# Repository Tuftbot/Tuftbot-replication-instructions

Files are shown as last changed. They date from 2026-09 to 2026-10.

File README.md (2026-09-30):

# Tuftbot replication instructions
In this repository you can find the technical documentation necessary to replicate the project Tuftbot, a robotic arm set up for tufting. Project developed during the project LAUDS Factory Open Call02 by Landscape Choreography and Lowpoly 

The project aims to establish an innovative microfactory model combining collaborative robotics with traditional textile craftsmanship to valorize European regional wool varieties which are mainly discarded. Primary objectives include developing a sustainable production system for artistic creation, optimizing robotic tufting for autochthonous wool processing, and creating a replicable model for small-scale textile manufacturing that bridges artisanal quality with automated efficiency. Through the development of robotic tufting technology the goal is to allow the activation of supply chains that can be local, from resource extraction to product retail, in order to keep the value produced within rural context. This model is opposed to global extractive value chains.

During the project LAUDS Open Call 2 Lowpoly and Landscape Choreography collaborated, with the support of SUPSI Fablab, to the development of a pilot for tufting with a robotic arm using local coarse wool. From the beginning the project was focused on optimising the work already developed by Lowpoly on robotufting with the requirements given by working with local coarse wool, and with the objective of designing a system replicable wherever there is access to a robotic arm.
To do so all the technical development was done in parallel at Lowpoly studio in Madrid, using an ABB IRB1200 model and at SUPSI Fablab in Medrisio using a KUKA KR6/16/20-3
In the Lowpoly setup, the robot is relatively small and mounted on a wheeled table. Since there are no significant spatial movement constraints, the robot can be moved around and beyond the studio, allowing the frames to be positioned almost 360° around it. In the SUPSI case, being the Fablab within a University, due to safety requirements also connected to the larger size and weight of the robot, the range of motion of the axes was limited. We therefore adapted the development of the project not only to the requirements given by each specific robot model but also to the restrictions given by the prototyping space.

In the following documentation you will find, in parallel, information on the two pilot tests developed.

In [01_Robot-Hardware.md](01_Robot-Hardware.md) you can find all the information on the hardware needed to replicate the Tuftbot.
In some cases you will find the links to the online shops where we acquired the components, for the custom made pieces you will find the 3D models that you will be able to further customise to your needs and 3D print.

In [02_Robot-Software.md](02_Robot-Software.md) you can find the links to the software we developed, links to the plug in we used and a explanation, piece by piece, of the grasshopper file we developed.

In [03_Tufting-equipment.md](03_Tufting-equipment.md) you can find a description of the tufting tools we opted for. One of the goal was to experiment with biobased and biodegradable materials. Like in other repositories you will find the link to the shops where we sourced our materials.

In [04_Comparing_two_set_up.md](04_Comparing_two_set_up.md) you can find a description of the two set up we experimented with. One in Madrid at Lowpoly studio using an ABB IRB1200 and one at SUPSI Fablab in Medrisio using a KUKA KR6/16/20-3.

In [05_Production_Workflow.md](05_Production_Workflow.md) you can find a step by step description of the workflow, from an image to the robot tufting process.

In [06_Native_coarse_wool.md](06_Native_coarse_wool.md) you can find a description of our research into native wool varieties, why is important for the project and the specifics of the yarns we developed.

In [07_Tiles_generator.md](07_Tiles_generator.md) you can find a description of the tiles generator we developed and link its Html file.

In [08_Tests_and_iterations.md](08_Tests_and_iterations.md) you can find a brief description of the evolution of the project, from first samples to final products. We chose to share this so it might help you in the adjustment that your specific replication project will require.

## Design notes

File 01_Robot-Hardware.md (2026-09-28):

## Hardware

### Robot minimum specifications

The payload needs to be minimum 3,5/ 5 kg in order to carry a 1kg gun in order to resist the backfire while tufting. 

Maximum printing area calculation according to robot dimensions

Given a certain arm extension the printing area can be calculated as follow:

| Type of robotic arm tested | Measures arm | Measures max tufting area |
| --- | --- | --- |
| KUKA KR6/16/20-3 | 1611 x 1320 x 138 mm | 1464 x 2025 mm |
| ABB IRB1200 | 539 x 869 x 115 mm  | 703 x 1102 mm |

- KUKA KR6/16/20-3:
  
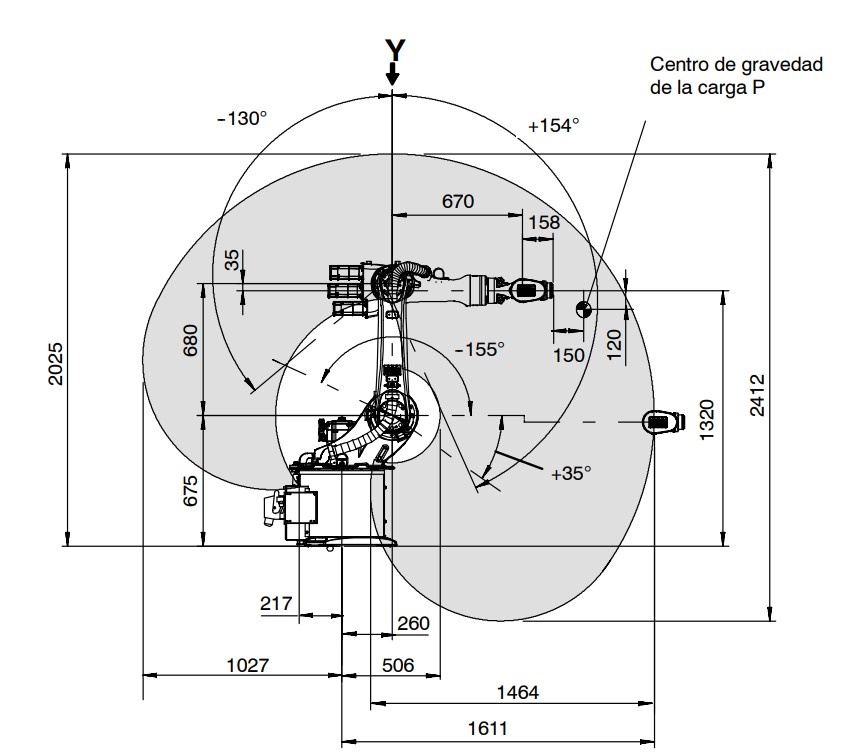
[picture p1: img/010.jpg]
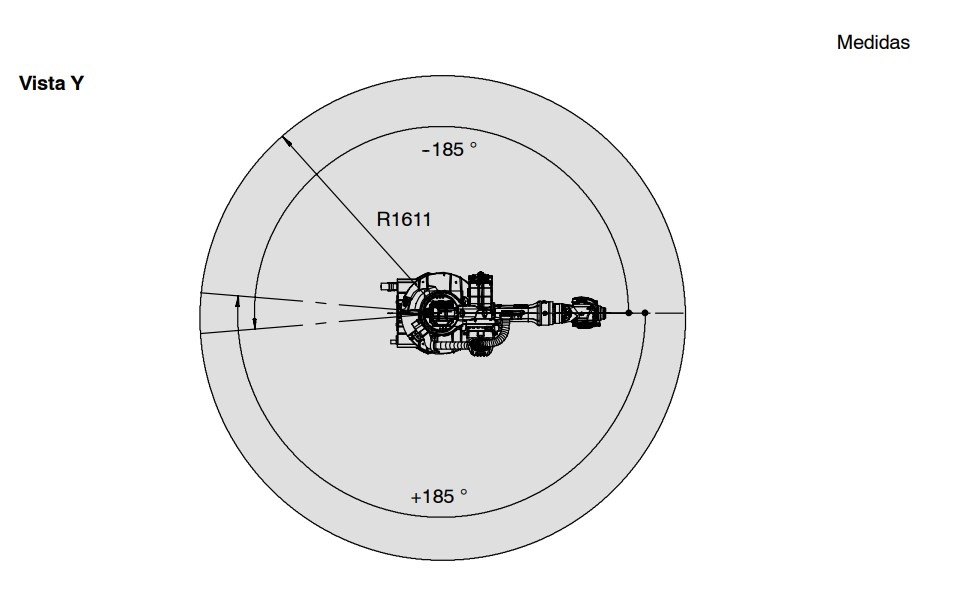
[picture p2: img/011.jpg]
  

- ABB IRB1200:

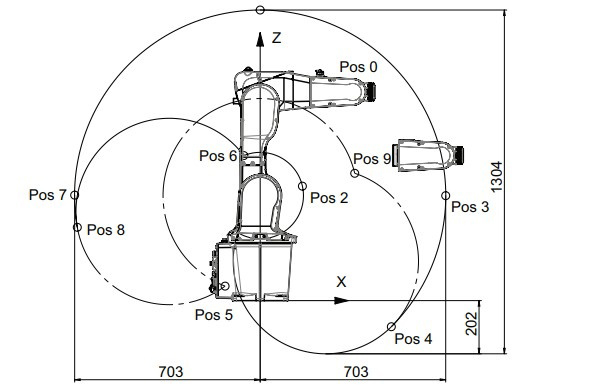
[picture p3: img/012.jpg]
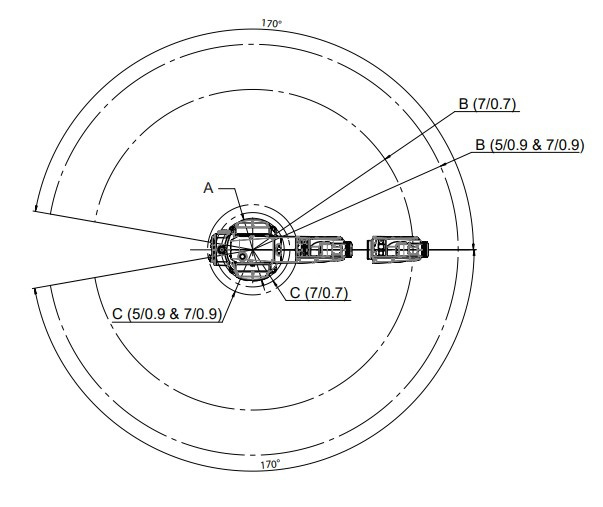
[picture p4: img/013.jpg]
    

### List of components 

### End effector 

The end effector is 3d printed. It is composed of two parts, one that gets attached to the robot and needs to be custom made for each robot, and one that is made for standard tufting guns. This second part has holes with a margin in order to adapt to the subtle differences of each gun. 

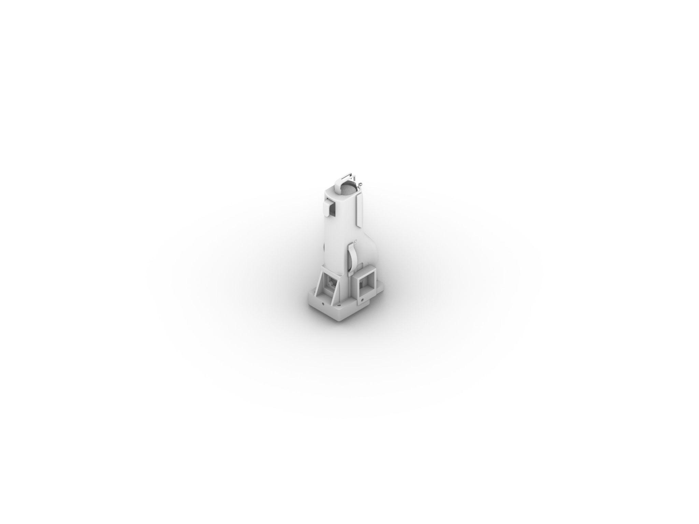
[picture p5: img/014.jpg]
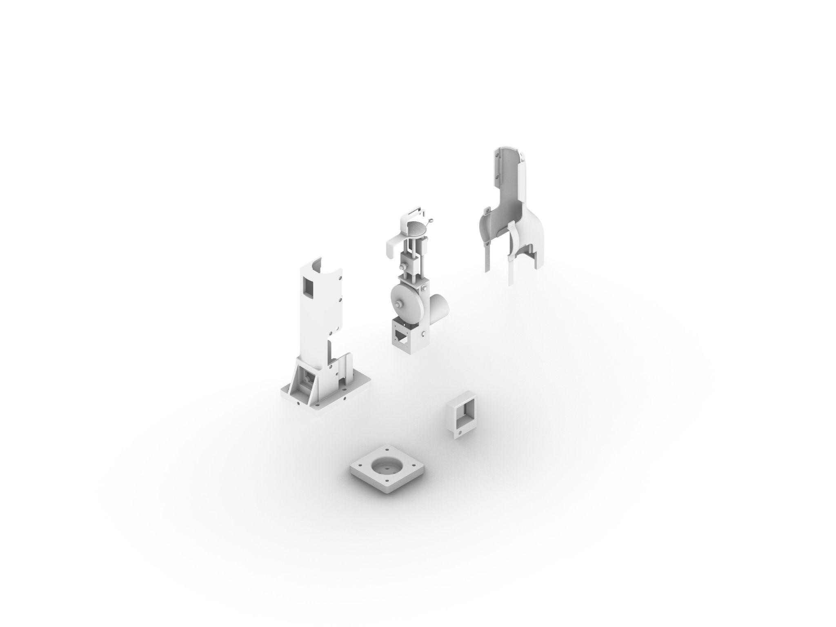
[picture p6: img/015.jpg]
 

To see 3d files go to this [folder](Files/Hardware-Files)

Here you can see an image of the end effector printed and mounted on the KUKA at SUPSI.

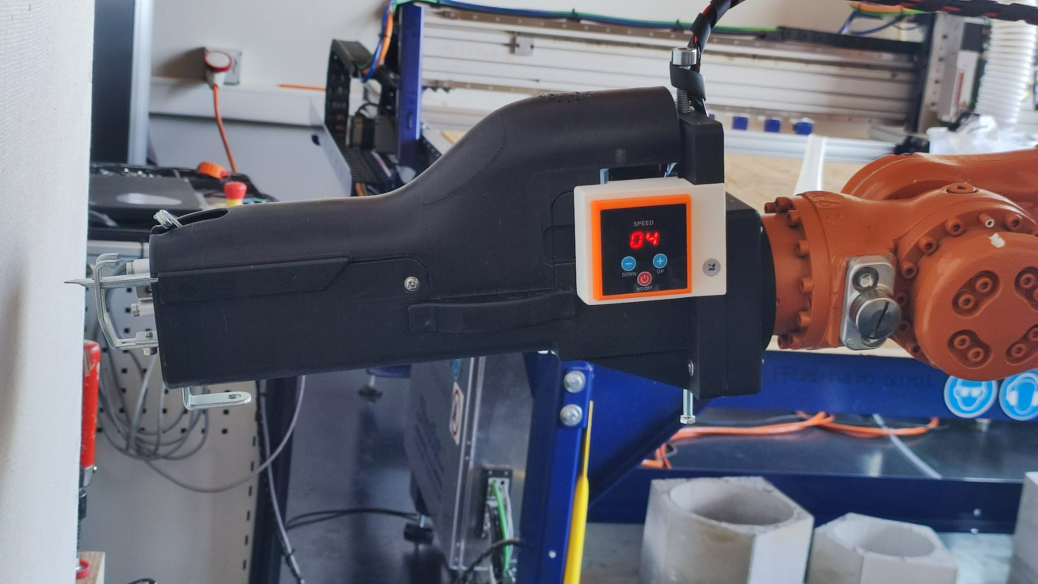
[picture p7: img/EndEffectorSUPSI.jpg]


 ### Sensors

We chose to test industrial sensors already used in textile machinery. There are two kinds of sensors, one to see if the yarn is present and one to detect if it’s moving. They are both fundamental to try to automatize the tufting process.

The robotic arm can turn the tufting gun on/off and read sensors that check if the yarn is running. Two sensors are used: a hall-effect sensor that detects rotation while yarn moves, and a vibration sensor that detects yarn motion; if either fails, the arm and gun stop so the operator can replace the yarn, then restart. However, the system can’t confirm that each stitch was actually inserted into the canvas, the gun’s own vibrations can trick the vibration sensor, and the hall-effect sensor can lose the yarn, making the whole stop–replace–restart flow unreliable.

The following sensors have been tested: [DC12-24V NPN PNP induction sensor Switch](https://it.aliexpress.com/item/1005002883343587.html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) and [Twisting Yarn Sensor Wire Device ](https://it.aliexpress.com/item/4000093115538.html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)

Vibration sensor with yarn

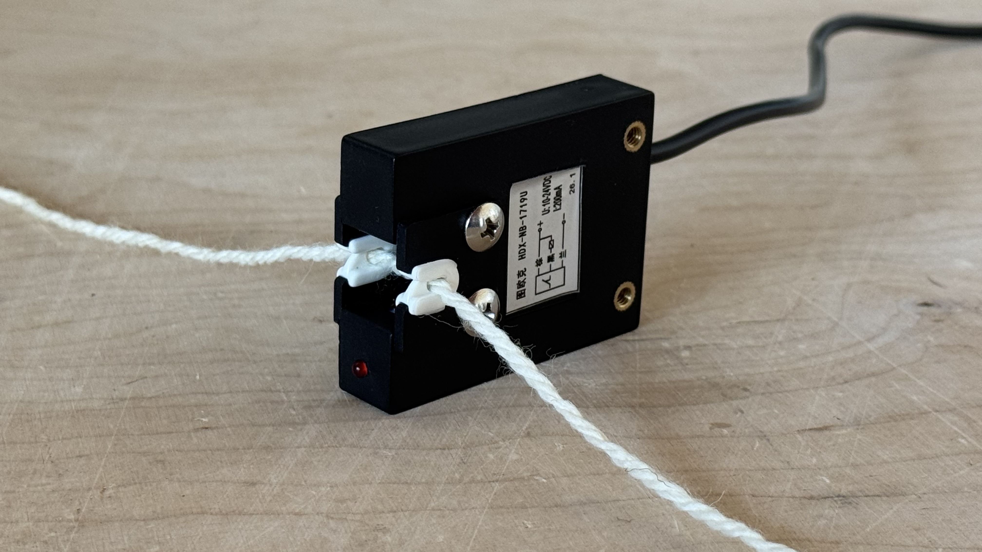
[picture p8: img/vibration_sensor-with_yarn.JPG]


Hall effect sensor with yarn

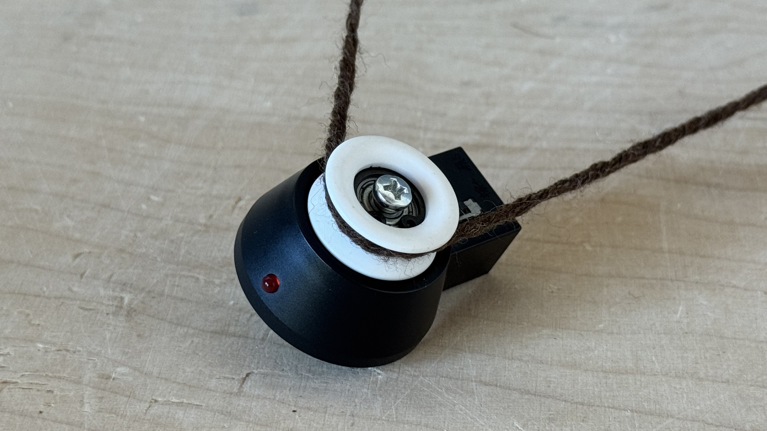
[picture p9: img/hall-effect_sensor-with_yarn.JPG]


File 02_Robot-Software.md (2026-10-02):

## Robot Software

### Links and plug in

[KUKA|prc (KUKA KR6/16/20-3)](https://www.food4rhino.com/en/app/kukaprc-parametric-robot-control-grasshopper)

Vectorize (package manager Rhino and plugin for grasshopper)

[Treesloth (package manager Rhino)](https://www.food4rhino.com/en/app/treesloth)

Robots (ABB IRB1200)(package manager Rhino)

[Image processing](Files/Software-Files/01_Image_processing)
A Grasshopper file used to convert the image into a toolpath.

[Robot Tufting KUKA](Files/Software-Files/02_Robot_Tufting_KUKA)
Grasshopper version for generating the code to be sent to the KUKA robot.

[Robot Tufting ABB](Files/Software-Files/03_Robot_Tufting_ABB)
Grasshopper version for generating the code to be sent to the ABB robot.

[Multiframe ABB Simulation](Files/Software-Files/04_Multiframe_ABB_Simulation)
Definition of Simulation for Multiframe Operations.

### Plugin install for KUKA
All the needed plugins can be automatically downloaded at the first opening of the Grasshopper file, one plugin will be missing called Treesloth, Treesloth1 or similar.

The plugin Treesloth needs to be downloaded by the provided link and the resulting GHA file should be manually moved into the componenets folder of Grasshopper.
You can open the folder by opening grasshopper then File > Special Folders > Component Folder
After moving the GHA file manually you can restart Rhino and the plugin will be installed

### General file usage
The file for ABB is using Robots as a plugin, this plugin can be used with most of the robotic arms. The KUKA version is using KUKA PRC that is specifically designed for KUKA robotic arms.
All the files are exported for Rhino8, in case you have a previous generation of rhinoceros you can use the plugin https://www.food4rhino.com/en/app/convert3dm to convert files

### Grasshopper code for single frame 

Image processing (JPEG format for correct script operation) using the Vectorize plugin, distinguishing between two zones: the one corresponding to the color white and the one corresponding to the color brown.

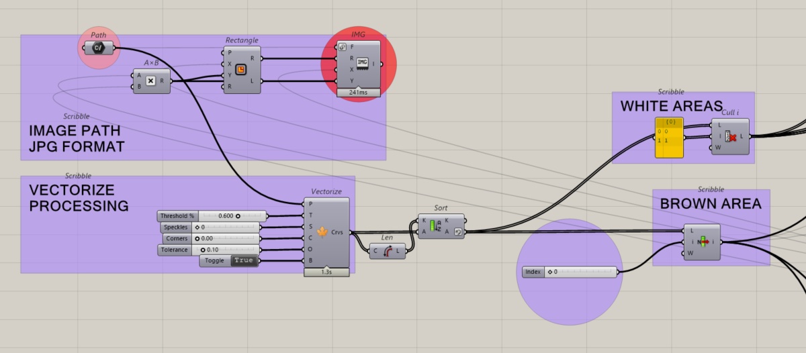
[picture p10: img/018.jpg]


The white areas are calculated by interpolating the outer lines, such that three curves are knitted for each of the shapes.

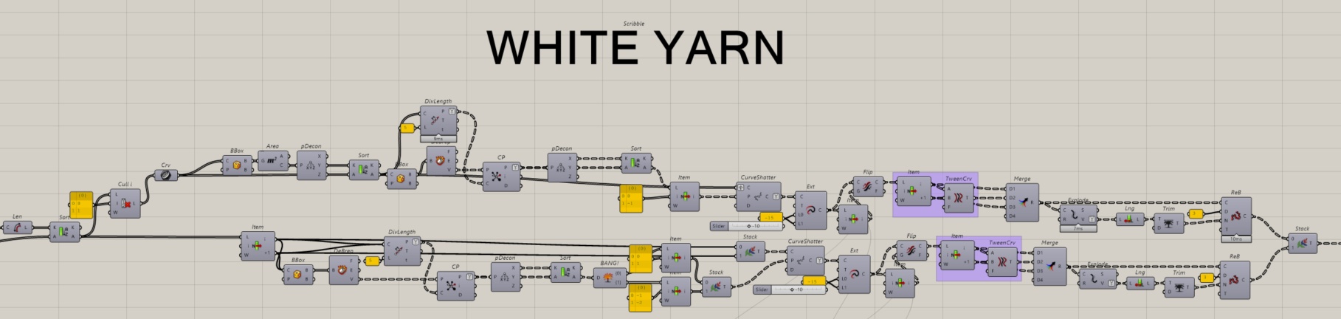
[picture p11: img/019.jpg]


In the brown area, a pattern of parallel lines is established with a minimum spacing of 5 mm to prevent the canvas from tearing. Where they intersect with white areas, the lines are interrupted and resume at the end of that area. Line segments shorter than 20 mm are omitted to prevent the canvas from tearing.

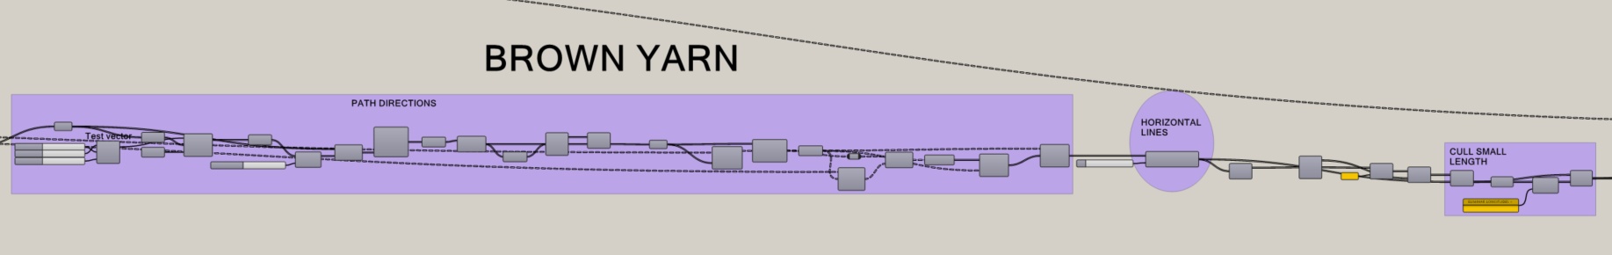
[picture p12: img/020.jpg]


The obtained curves are organized into two blocks (white/brown), and the direction of the curves, which the robot will follow, is established.
The file containing the curve geometry is divided into two main blocks. 

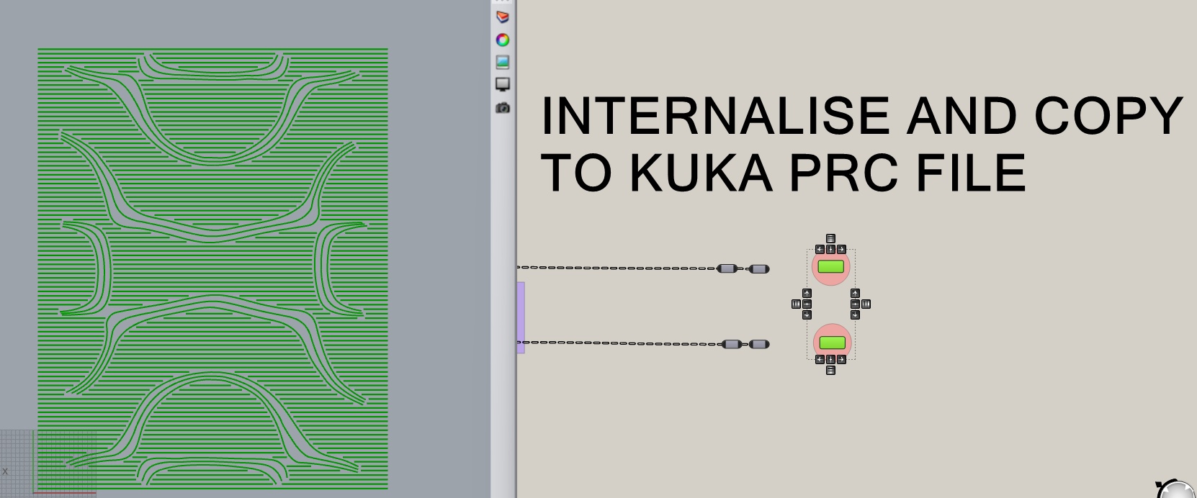
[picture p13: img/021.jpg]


The two curve blocks are oriented and positioned. The curves are converted into polylines to adjust the robot's movement precision.

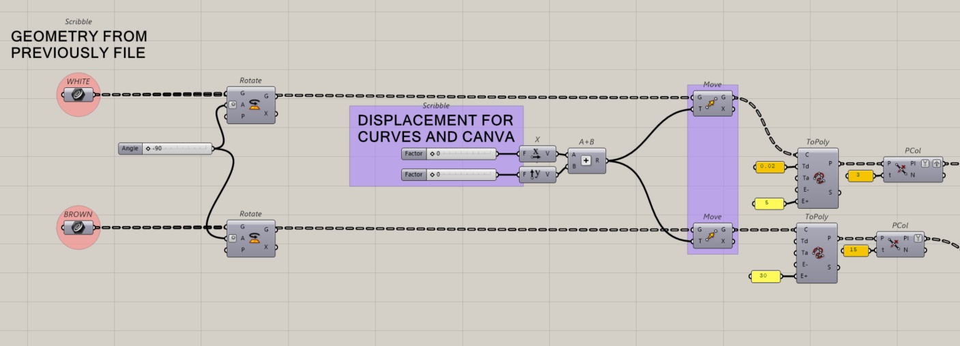
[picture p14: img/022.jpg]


The initial and final positions of the robot are established.

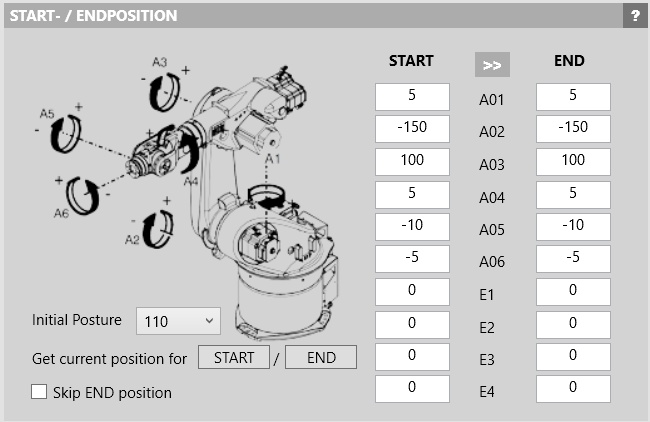
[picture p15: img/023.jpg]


We include an initial calibration point that aligns with one of the frame's corners. This allows the frame's position to be verified, or readjusted if necessary, at the start of the program's execution.

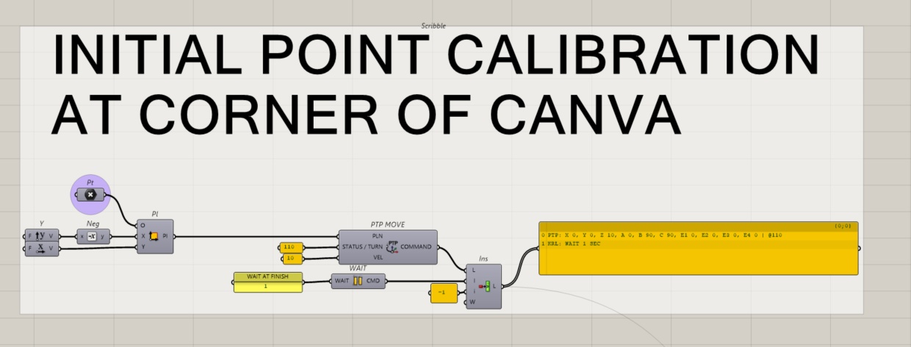
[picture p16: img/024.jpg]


The robot begins tufting the white lines. Digital output pins are used to activate and deactivate the tufting gun, as well as to light up a green indicator lamp showing that the robot is in operation.

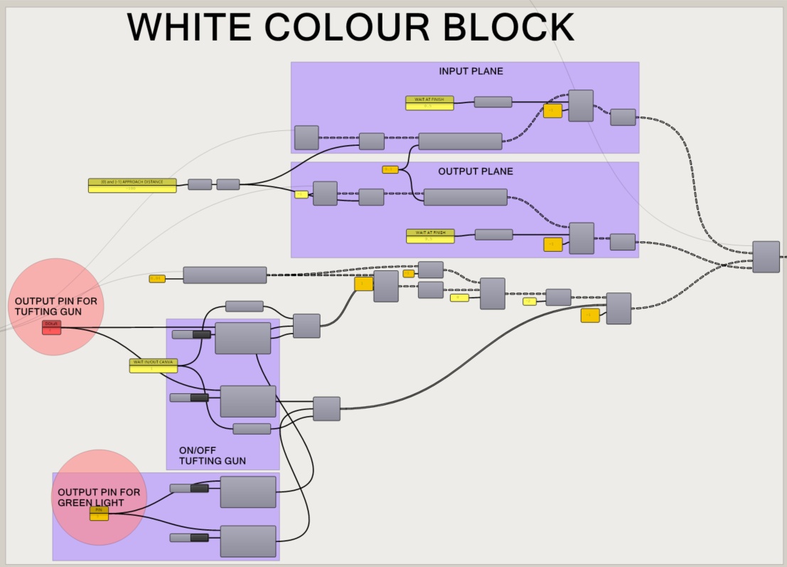
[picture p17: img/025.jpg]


When the first block is completed, the robot deactivates the green DO, activates the red DO, and moves to a preset rest position to proceed with the thread color change.
Once the thread has been changed, a pushbutton, configured via a DI, must be used to make the robot resume movement.

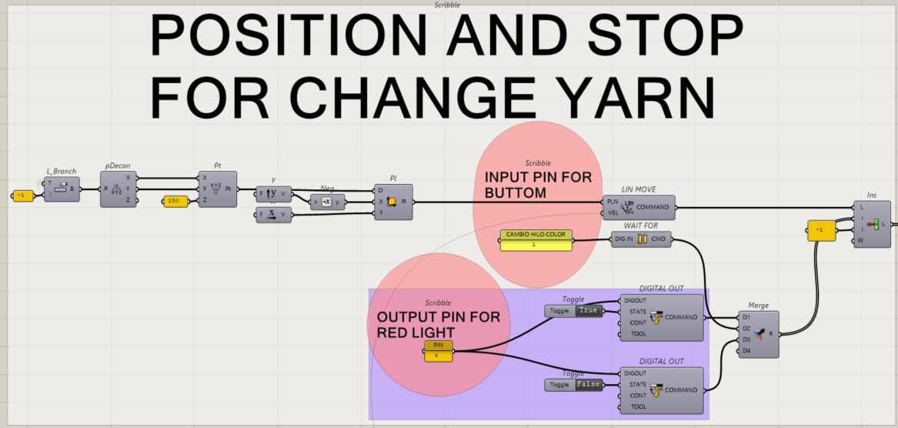
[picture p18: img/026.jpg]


The robot begins weaving the brown lines. Digital output (DO) pins are used to activate and deactivate the tufting gun, as well as to light up a green indicator showing that the robot is in operation. Once finished, the robot returns to its starting position.

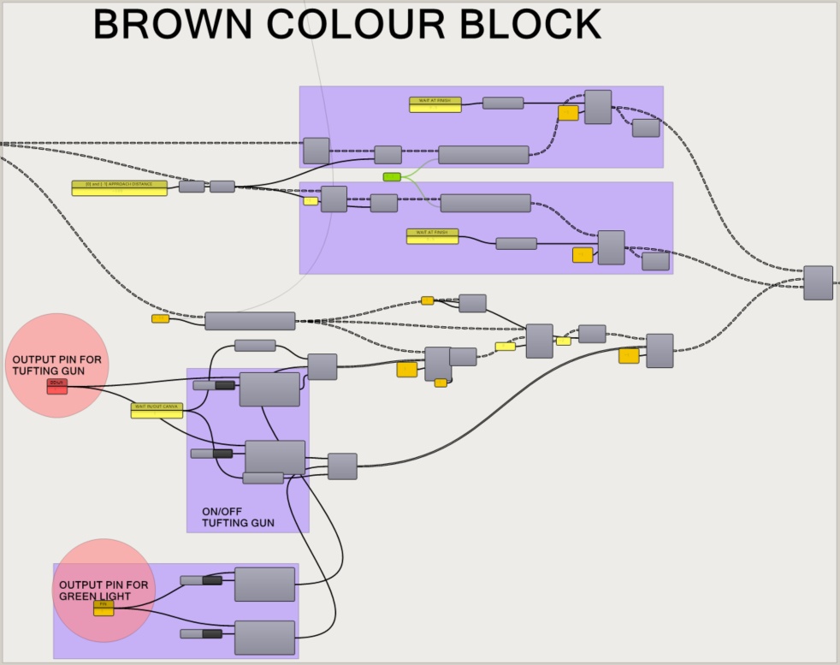
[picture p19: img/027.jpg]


All planes and commands to be executed by the robot are connected to the KUKA|prc CORE component. The geometry of the gun is also connected to it, allowing us to simulate the toolpath and verify whether the canvas position is correct, check for collisions, singularities, etc., and make any necessary corrections.

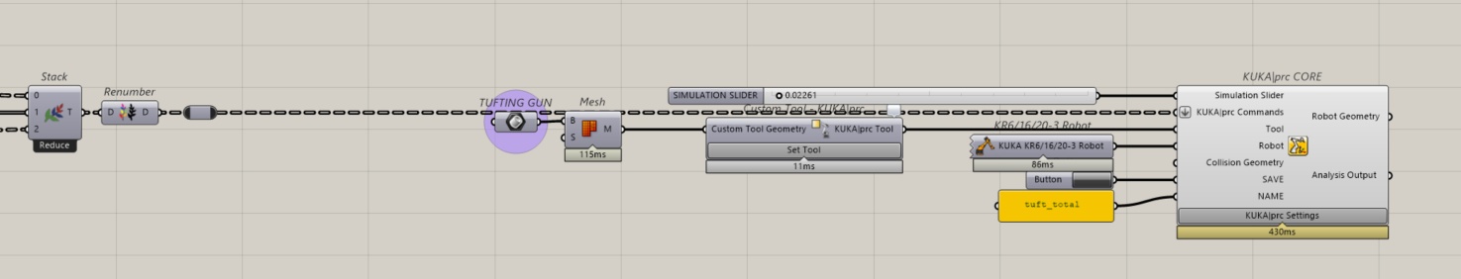
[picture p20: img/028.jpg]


### Grasshopper code for multi frame

The workflow for the multi-frame system follows the same steps previously described for image processing.
The robot executes the white thread lines for both frames, pauses to switch threads, and finally executes all the parallel brown lines for both frames.
This scenario has been simulated using the ABB IRB1200 robot.

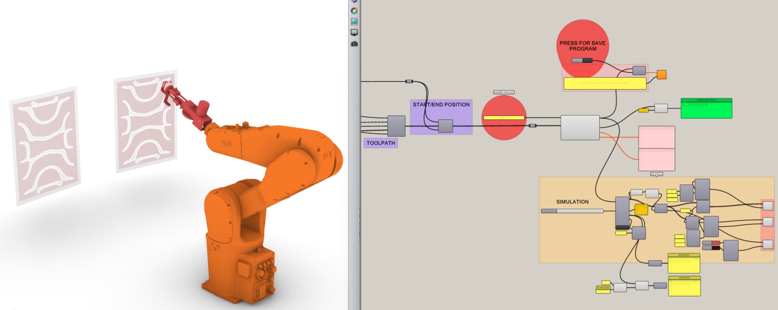
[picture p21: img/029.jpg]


The geometry of both frames connects to the "Create program" component of the Robots plugin, allowing us to simulate the toolpath and verify the positioning of both canvases, checking for collisions, singularities, and the like, so that any issues can be corrected.

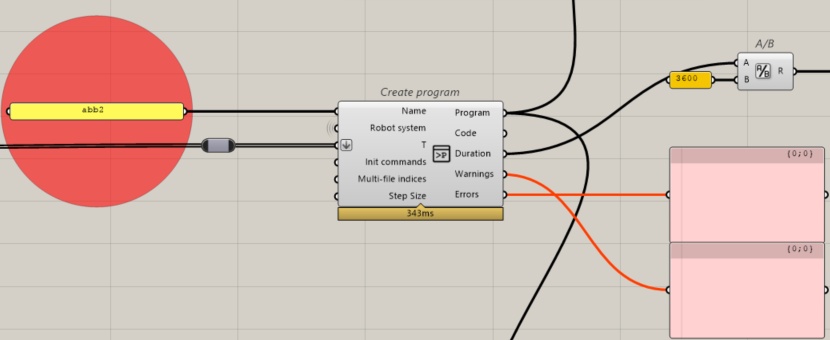
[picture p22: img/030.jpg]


### Description on how to make the set up and use it to tuft

Position the frame according to the base coordinates specified in KUKA|prc CORE.
When the toolpath .src file is executed for the first time, the initial position assumed by the robot serves as the final calibration.

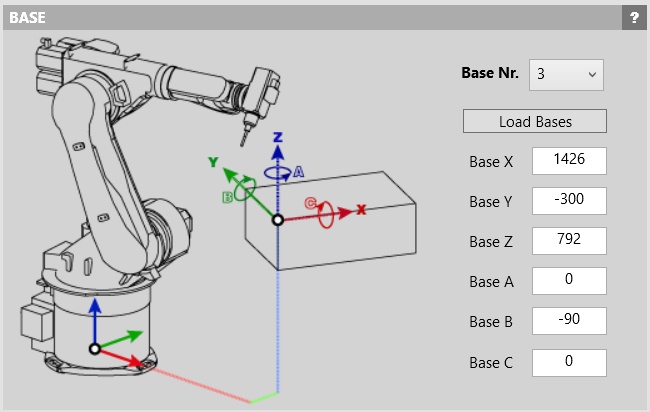
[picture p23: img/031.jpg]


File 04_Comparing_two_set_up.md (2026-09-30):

### Comparing two set up

Set up at Lowpoly in Madrid (left), Set up at SUPSI Fablab in Mendrisio (right).

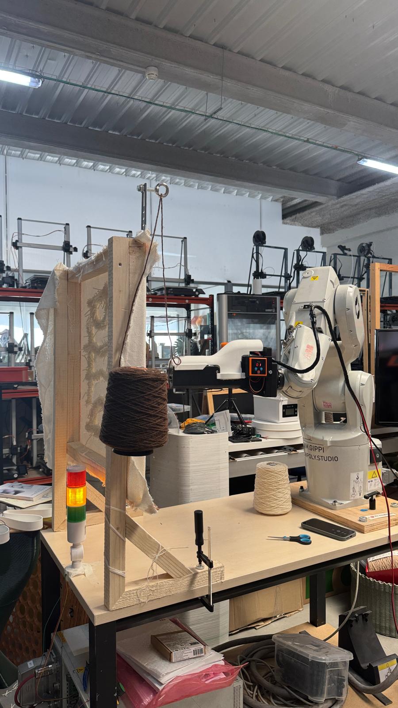
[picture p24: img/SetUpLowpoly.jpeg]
 

Both prototypes are based on the same image (JPEG format, to ensure the script works correctly).
The drawing was done by Eva Failla di [Studio Converter](https://studioconverter.com/).

 

The image undergoes vectorization using the Vectorize plugin, distinguishing between two zones: the one corresponding to the color white and the one corresponding to the color brown.



The lines are spaced at least 5 mm apart to prevent the canvas from tearing during the execution of the pattern.
Line segments shorter than 20 mm are omitted to avoid tearing the canvas.
The resulting curves form the toolpath that the robot will follow. In Mendrisio, this is carried out using a KUKA KR6/16/20-3 model, while in Madrid, an ABB IRB1200 model is used.
The image used at both locations measures 400 x 500 mm.
The positioning of the robot relative to the frame holding the canvas is as follows:

Mendrisio (KUKA KR6/16/20-3):





Madrid (ABB IRB1200):



An end effector with the tufting gun is attached to the flange of both robot models, with the TCP configured as follows:

Mendrisio (KUKA KR6/16/20-3):



Madrid (ABB IRB1200):



## Single frame and multi frame options - What to bare in mind

In single-frame mode, the frame holding the canvas is positioned facing the robot, within the effective working area.

In multi-frame mode, simulated in Madrid using the ABB IRB1200 robot, both canvases are placed facing the robot, one after another with a 22 cm separation, as shown in the image.



## Space minimum requirements

The frame and canvas must be positioned within the effective working area. 
Using the KUKA|prc CORE component within the script, we can visually verify whether the position is reachable throughout the entire toolpath.
If the component appears gray, the position is correct, and the robot can reach all positions.
If the component turns orange, the robot encounters a singularity while attempting to reach a position; therefore, it is advisable to readjust the position.
If the component turns red, the canvas position lies outside the effective working area and requires modification.



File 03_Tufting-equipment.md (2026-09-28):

## Tufting equipment

### Tufting gun specifics

Currently this standard hand tufting gun has been tested: 
45mm Electroacupuncture Long Velvet Tufting Gun Cutting Loop Velvet Carpet Weaving Machine 4-25 Needle Steps Shuttle Loom Tool and the end effector has been designed accordingly.

At this  [link](https://it.aliexpress.com/item/1005010391053075.html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) you can find the gun we worked with. 



### Sustainable canvas options

Typically canvas used for tufting are done with synthetic fibers (polyester), we have been looking into sustainable biobased alternatives available on the market and cotton and jute are the main alternatives. Here some links to shops 
[100% cotton](https://tuftingshop.com/it/collections/tufting-cloth/tuftingcloth
)

[100% Jute](https://tuftbox.co.uk/collections/tufting-fabric/products/hessian-rug-fabric-premium-woven-jute-for-handmade-rugs)

We also tested a cloth made of wool acquired second hand to produce a monomeric sample. Because of the characteristic of the material we were able to test wet felting technique as an alternative backing system to the use of glue. 

Here you can see samples of tufting with coarse wool on a wool canvas.





### Sustainable adhesive options

Most common adhesive used for backing the tufted pieces are PVC based. We searched for sustainable biobased alternatives available on the market and we identified [natural latex](https://tuftbox.co.uk/blogs/guides/synthetic-vs-natural-latex-rug-tufting-glue
) as the most sustainable option.

We also identified other adhesives for this purpose which are defined as sustainable but we couldn’t access the full list of ingredients for copyright reasons and so we decided to use natural latex as adhesive for our samples and prototypes.



### Bobin set up for single frame and multiframe

The prototypes realised, both at Lowpoly and SUPSI Fablab, have been testing only the single frame set up. In this scenario the best identified option has been placing the bobbins on the floor on the left side of the frame, the yarn from there goes through a hook screwed on the top left corner of the frame, before entering the gun. This is a quite standard set up used in manual tufting. While the robot movement for a multiframe set up has been tested digitally via printing simulations, the positioning of the bobbin and the path of the yarns can’t be tested because there are no options for yarn movement digital simulation.

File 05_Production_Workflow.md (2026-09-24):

## Production Workflow 

1 - Image processing (JPEG format for correct script operation) using the Vectorize plugin, distinguishing between two zones: the one corresponding to the color white and the one corresponding to the color brown.

  

2 - In the brown-colored area, a pattern of parallel lines is established with a minimum spacing of 5 mm to prevent the canvas from tearing. Where they intersect with white-colored areas, the lines are interrupted and resume on the other side of the area. Line segments shorter than 20 mm are omitted to avoid tearing the canvas.

3 - The white-colored areas are woven by interpolating the outer lines, such that three curves are woven for each of the shapes.

4 - The obtained curves are arranged into two blocks (white/brown), and the direction of the curves, which the robot will follow, is established.

5 - The file containing the curve geometry is divided into two main blocks. 

6 - The robot's initial position is established, and a first point, serving as a calibration reference, is included to coincide with one of the frame's corners. This allows the frame's position to be verified at the start of program execution to determine whether it is correct or requires readjustment.

7 - The robot begins tufting the white lines. Digital output pins are used to activate and deactivate the tufting gun, as well as to light up a green indicator lamp showing that the robot is in operation.

8 - When the first block is finished, the robot deactivates the green DO, activates the red DO, and moves to a configured rest position to proceed with the thread color change.

9 - Once the wire has been changed, a push-button must be used, configuring a digital input (DI), for the robot to restart the robot´s movement.

10 - The robot begins tufting the brown lines. Digital output (DO) pins are used to activate and deactivate the tufting gun, as well as to light up a green indicator showing that the robot is in operation. Once finished, the robot returns to its starting position..

### Troubleshooting and commons errors

The script correctly reads the image when it is in JPEG format. Complex images can be difficult for the Vectorize plugin to process.

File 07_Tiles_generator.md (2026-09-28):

## Tiles generator

Zoe Romano worked on the development of a HTML based software to automatise the design of tufted tiles which export the required files for the robotufting process.
Hexweave is a self-contained, single-file web application written entirely in HTML, CSS, and vanilla JavaScript with no frameworks, no build tools, no dependencies.

The visual interface (layout, controls, typography) is built in HTML5 and styled with CSS3, using CSS custom properties (variables) for the design token system, CSS Grid and Flexbox for the responsive layout, and CSS keyframe animations for the flash ring interaction feedback.

The geometry engine is pure JavaScript (ES2020). It computes a flat-top hexagonal tessellation grid analytically, deriving each tile's centre coordinates, edge midpoints, and outward normal vectors in real time, and renders the Van Ness cord matchings as cubic Bézier curves, with handle lengths scaled proportionally to each chord for consistent curvature across adjacent, skip-1, and opposite edge pairings.

The drawing surface is an SVG (Scalable Vector Graphics) element built dynamically by the JavaScript, which constructs and inserts SVG path elements directly into the DOM on every state change. There is no canvas rasterisation and no pixel data, the entire graphic is resolution-independent vector geometry.

The interactivity, using sliders, dropdowns, single-click rotation, double-click class cycling, and the reshuffle function, is handled through native browser DOM events with no external libraries. The download buttons generate SVG files client-side by encoding the geometry as a data: URI and triggering a programmatic anchor click.

[Here](Files/hexweave_tuftbot_final.html) you can fine the Html file for the Tile generator which you can download and run on your browser and [Here](https://htmlpreview.github.io/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) a visualization to test it.

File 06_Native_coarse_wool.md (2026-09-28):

## Native coarse wool
### Yarn specifications

Critical to project success was identifying specific yarn parameters for coarse mountain wool compatibility: torsion specifications, fiber structure requirements, cone configuration, and handling protocols. By translating traditional shepherd and artisan knowledge into technical specifications, we created a bridge between pastoral practice and robotic precision. These parameters ensure the technology enhances rather than rejects local material culture.

During the project we worked with wool sourced from [Associazione pecora brogna della lessinia](https://www.pecorabrogna.it/) and we produced the following yarns titles:  2/3500 - 3/3500 - 2/2/2/14000 -  3/2/2/14000.

First batch of yarns produced with naturally brown wool.
These yarns were hand-tuft and robo-tuft to test them and became instrumental to definition of the final yarns.



Second batch of yarns produced with naturally white wool from Pecora Brogna.



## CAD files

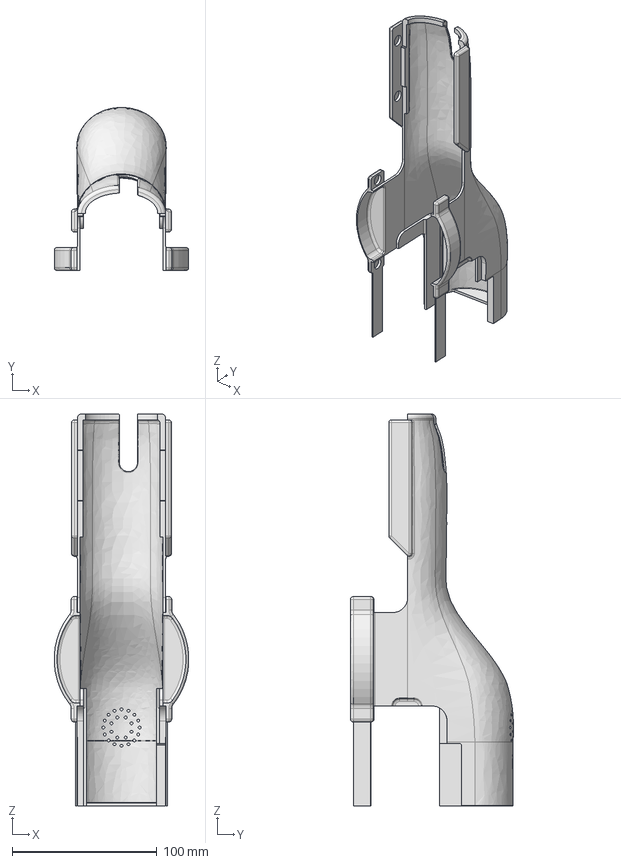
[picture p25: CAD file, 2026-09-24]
Files/Hardware-Files/cover/covertufting.stp
92.8 x 112.6 x 270.5 mm

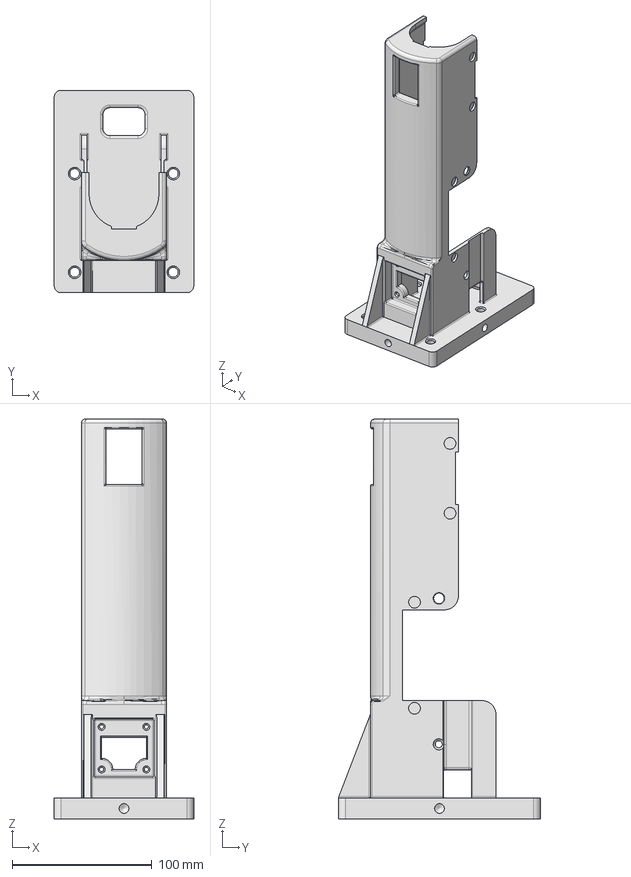
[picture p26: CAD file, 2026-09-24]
Files/Hardware-Files/frame/estructuratufting.stp
100.0 x 145.0 x 286.5 mm

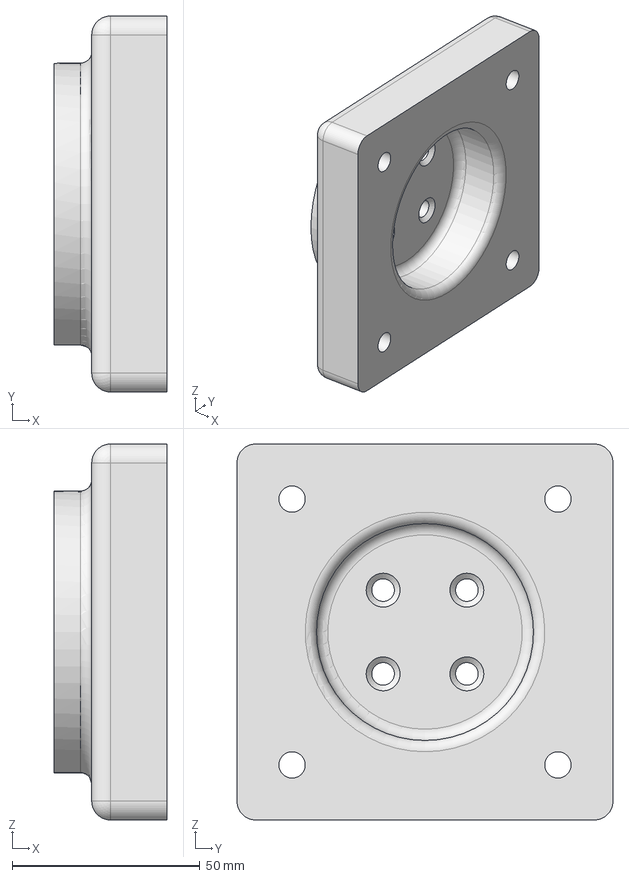
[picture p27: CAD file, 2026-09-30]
Files/Hardware-Files/robot flange/ABB/ABB_flange.stp
30.0 x 100.0 x 100.0 mm

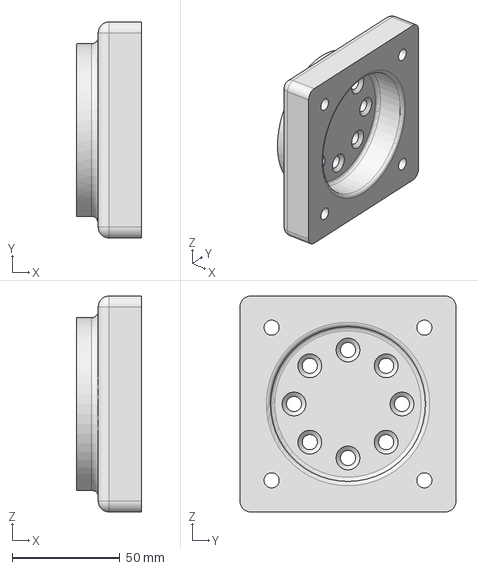
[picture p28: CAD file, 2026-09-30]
Files/Hardware-Files/robot flange/KUKA/KUKA_flange.stp
30.0 x 100.0 x 100.0 mm

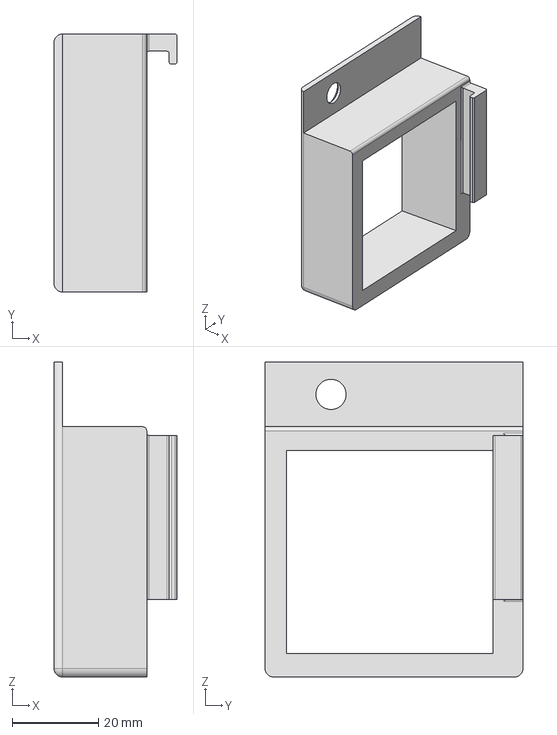
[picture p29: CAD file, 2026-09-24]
Files/Hardware-Files/screen cover/cajetinparapantalla.stp
28.5 x 59.8 x 73.0 mm

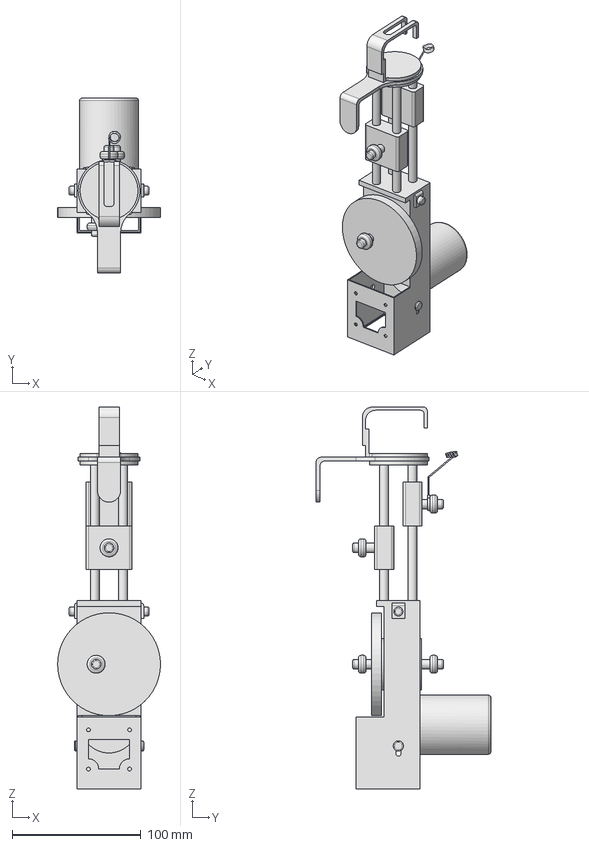
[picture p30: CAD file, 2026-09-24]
Files/Hardware-Files/tufting gun/pistola.stp
79.9 x 136.0 x 297.0 mm

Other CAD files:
Files/Hardware-Files/cover/covertufting.igs
Files/Hardware-Files/cover/covertufting.ipt
Files/Hardware-Files/cover/covertufting.obj
Files/Hardware-Files/cover/covertufting.stl
Files/Hardware-Files/frame/estructuratufting.igs
Files/Hardware-Files/frame/estructuratufting.ipt
Files/Hardware-Files/frame/estructuratufting.obj
Files/Hardware-Files/frame/estructuratufting.stl
Files/Hardware-Files/robot flange/ABB/ABB_flange.igs
Files/Hardware-Files/robot flange/ABB/ABB_flange.ipt
Files/Hardware-Files/robot flange/ABB/ABB_flange.obj
Files/Hardware-Files/robot flange/ABB/ABB_flange.stl
Files/Hardware-Files/robot flange/KUKA/KUKA_flange.igs
Files/Hardware-Files/robot flange/KUKA/KUKA_flange.ipt
Files/Hardware-Files/robot flange/KUKA/KUKA_flange.obj
Files/Hardware-Files/robot flange/KUKA/KUKA_flange.stl
Files/Hardware-Files/screen cover/cajetinparapantalla.igs
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

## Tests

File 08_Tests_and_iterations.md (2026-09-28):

## Tests and iterations

The project was made through a series of tests and iterations, moving from hand tufting samples to robotic tufting and back.
Here you can find a series of images of the different tests developed between Milan, Madrid and Mendrisio.

Hand tufted test of the first batch of yarns produced. 
With these samples we were trying to understand optimal tuftig speed and distance between the lines.
These information were used in setting the robo-tuft.

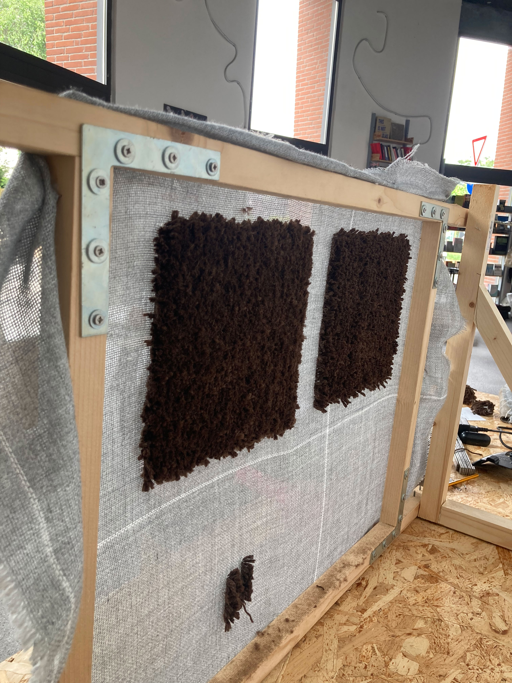
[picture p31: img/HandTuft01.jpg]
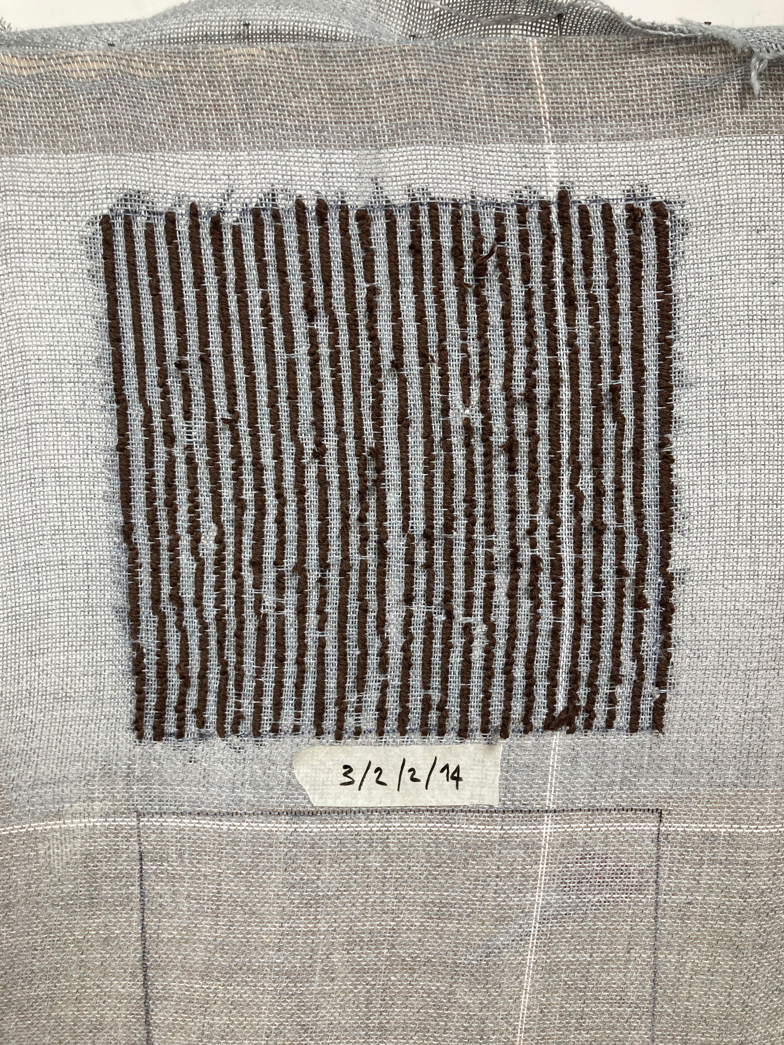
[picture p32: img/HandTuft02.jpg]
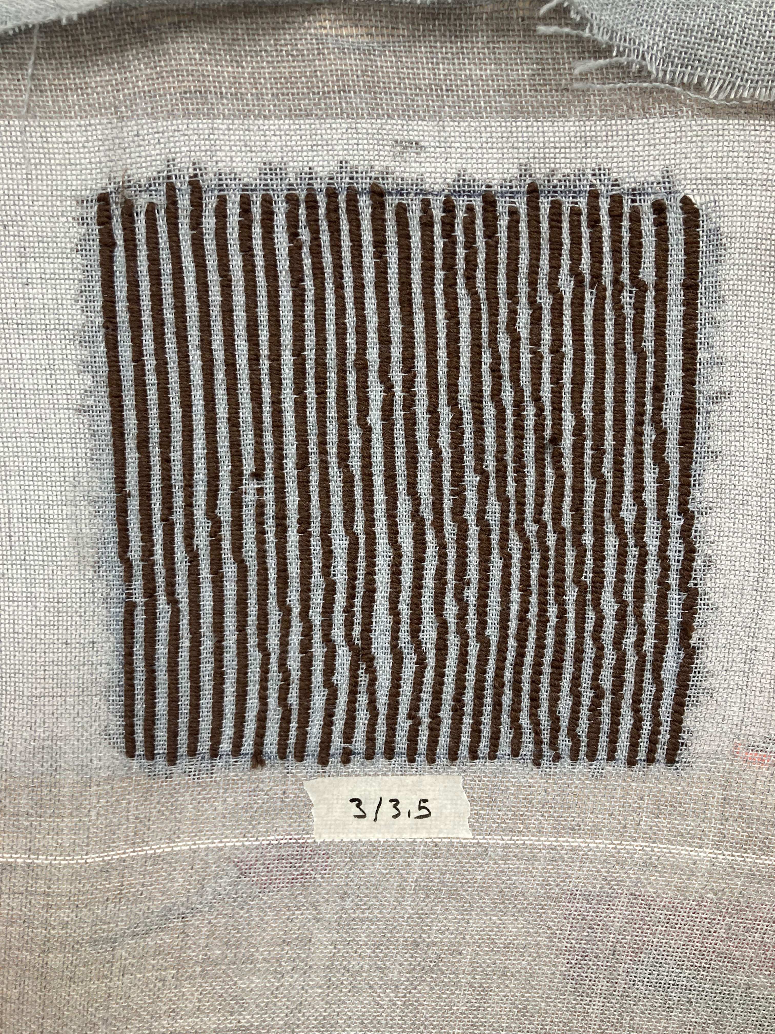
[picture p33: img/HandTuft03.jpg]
  

After the production of plain samples to do basic set up of the Tuftbot we moved toward tufring more complex geometries with two colours.
We used a drawing developed by Eva Failla di [Studio Converter](https://studioconverter.com/) in both set up, Madrid and Mendrisio.
This step was fundamental to test the software that generate the tufting path from an image and define the lines resolution.

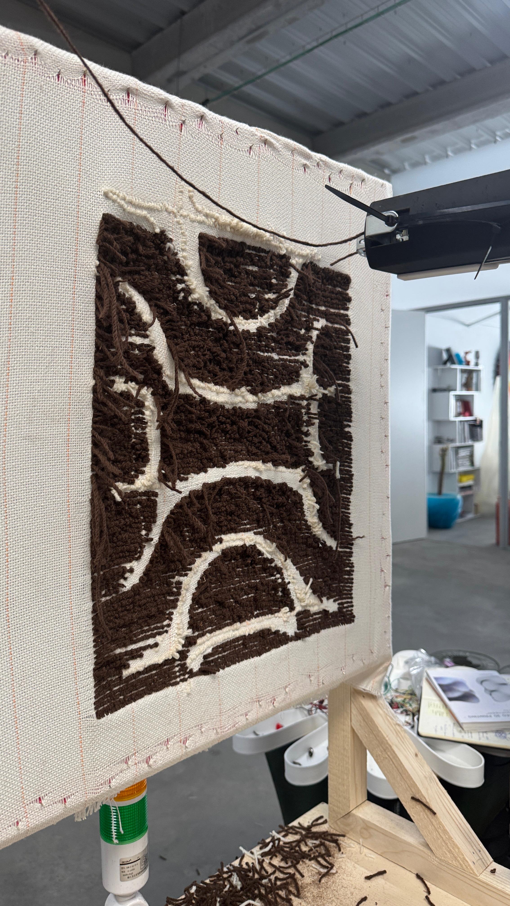
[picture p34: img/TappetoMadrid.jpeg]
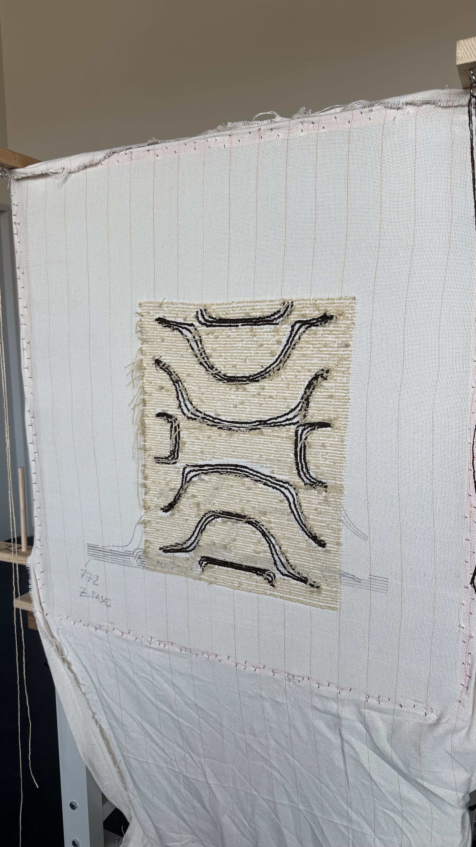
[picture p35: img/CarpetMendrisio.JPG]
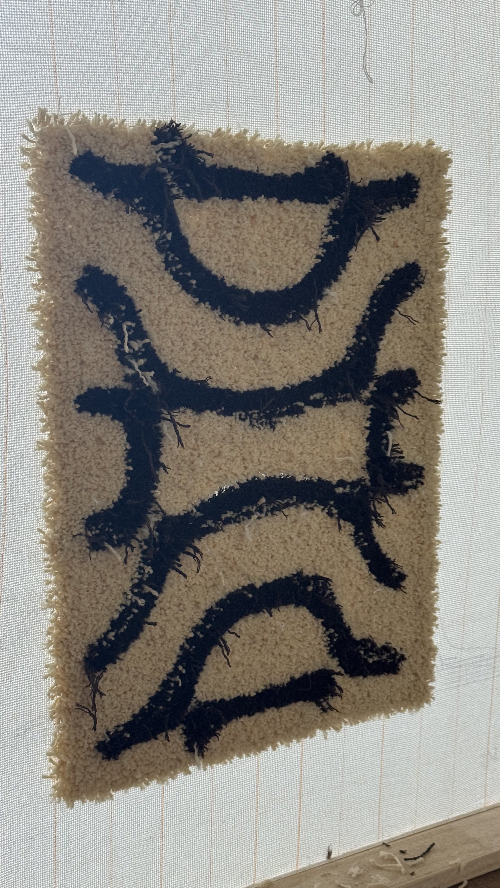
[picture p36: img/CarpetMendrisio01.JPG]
  

Finally with the feedbacks gainend by printing Studio Converter Piece we produced a set of tiles which compose a modular tapestry. The tiles graphic has been produced using the developed tiles generator Hexweave.

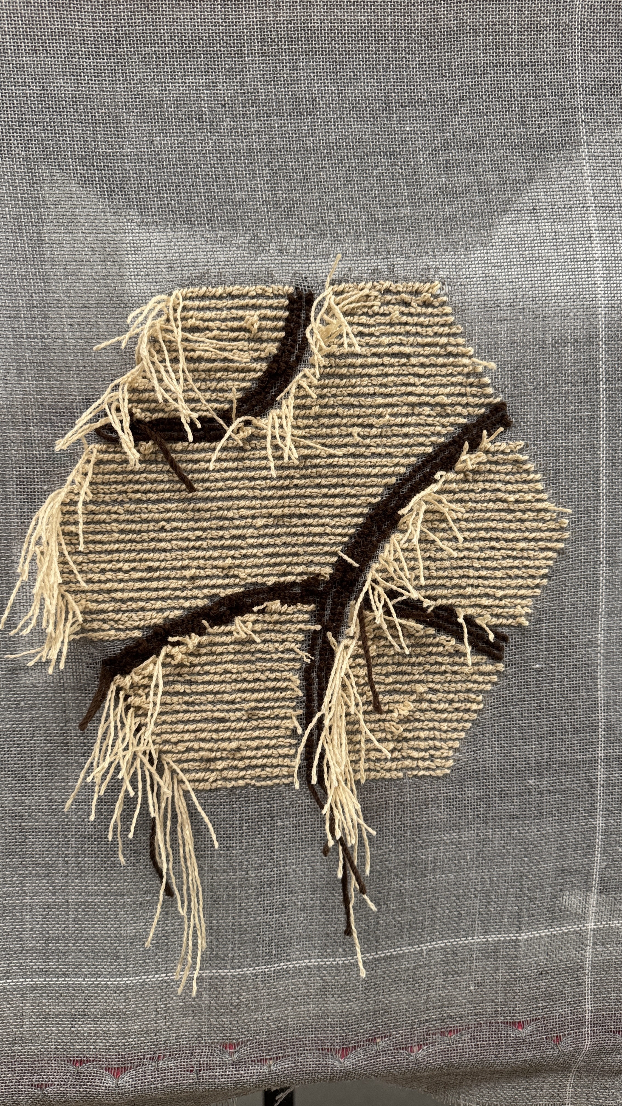
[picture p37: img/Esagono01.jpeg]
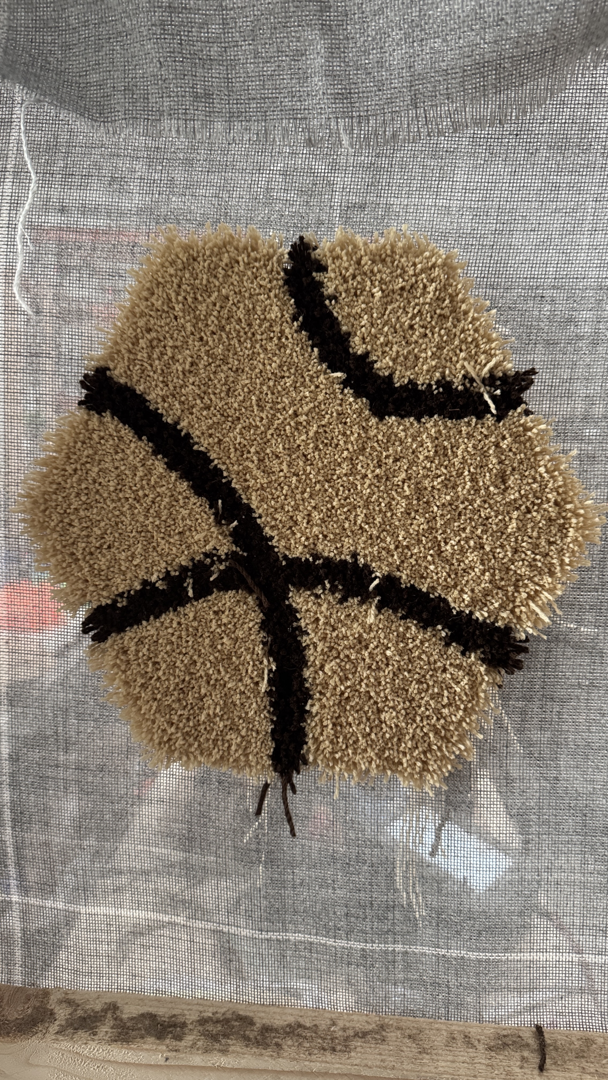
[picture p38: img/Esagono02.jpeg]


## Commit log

2026-09-24 rename folders
    [01_TUFTING_IMAGEN.3dm, 02_TUFTING_KUKA_PRC.3dm, 03_TUFTING_ABB.3dm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]
2026-09-30 robot adapter
    [ABB_flange.igs, ABB_flange.ipt, ABB_flange.obj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]
2026-10-02 new files
    [DGF_HEX.3dm, HEX_TUFTING_KUKA_PRC.3dm]
2026-10-02 new folder
    [DGF_HEX.3dm, HEX_TUFTING_KUKA_PRC.3dm]
